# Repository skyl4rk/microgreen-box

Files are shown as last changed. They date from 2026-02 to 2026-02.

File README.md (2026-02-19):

# Microgreen Box

**An open-source, automated device that grows broccoli microgreens daily — on solar power, in a vehicle, or at home.**

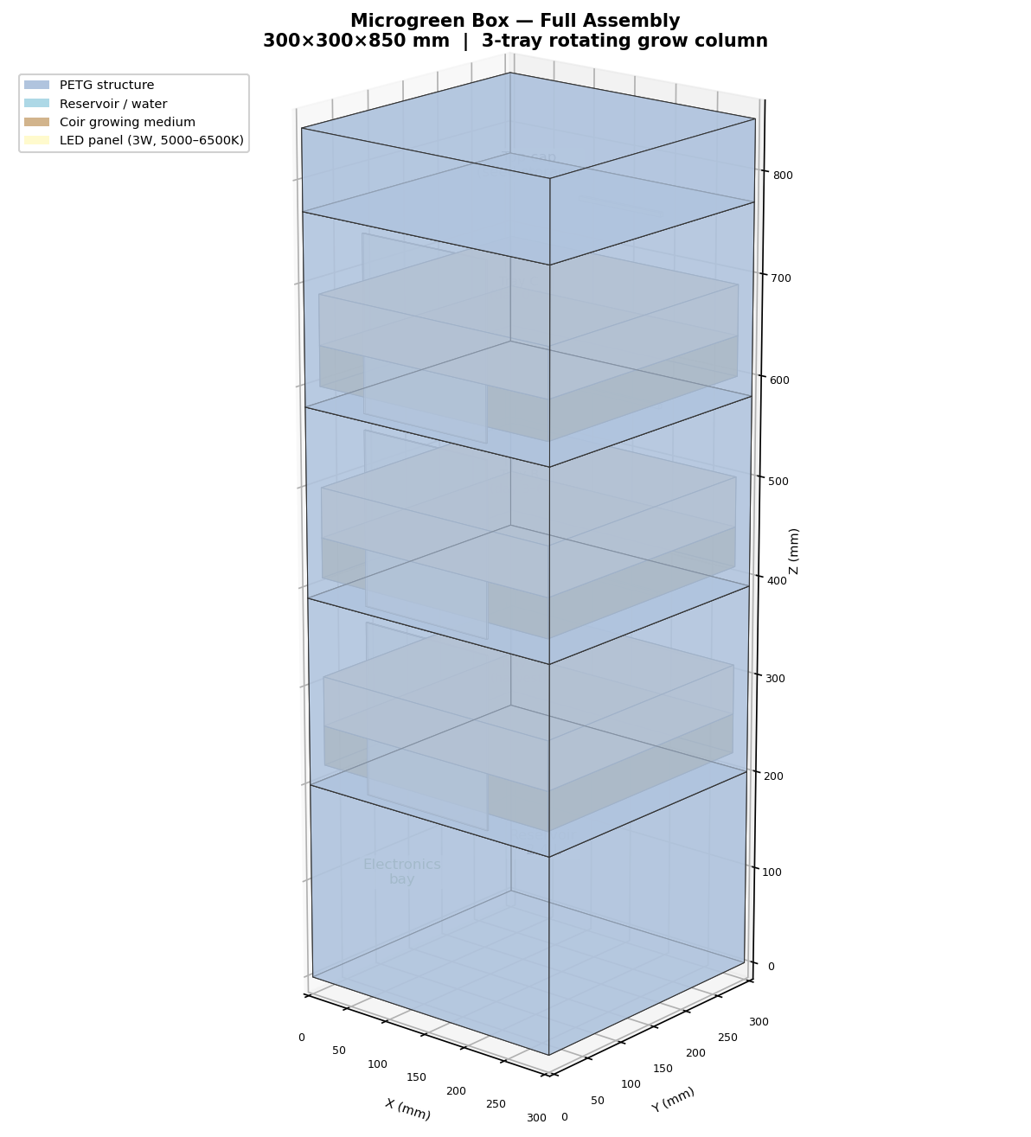
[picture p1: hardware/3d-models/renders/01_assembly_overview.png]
Assembly Overview


Broccoli microgreens contain up to 100× more sulforaphane than mature broccoli — one of the most-studied anti-cancer, anti-inflammatory compounds in food. This device automates the full grow cycle so you harvest 30 g of fresh greens every morning without daily attention.

---

## What it produces

| Output | Value |
|---|---|
| Species | Broccoli (*Brassica oleracea* var. *italica*) |
| Daily yield | 30 g/day (up to 60 g/day with 4 trays) |
| Sulforaphane dose | ~200 µmol/day (upper end of clinically studied range) |
| Grow cycle | 10 days seed-to-harvest |
| Rotation | 3 trays staggered; harvest one tray every ~3 days |
| Consumption | Raw in a morning smoothie (blending maximises sulforaphane) |

---

## Key features

- **Fully automated** — timed LED lighting, twice-daily moisture-feedback watering, harvest alert
- **12V DC power** — runs on solar + LiFePO4 battery, vehicle 12V, or a mains adapter
- **Vehicle-compatible** — sealed water system, no open surfaces, wide low-CG base
- **3D-printable** — all parts fit on a 200×200mm print bed; ~2.5 kg PETG
- **ESP32 firmware** — Arduino framework, light-sleep power management, optional OLED display, serial debug
- **Modular** — add a 4th tray ring to double output; no other changes needed
- **Open hardware** — full OpenSCAD parametric models, wiring schematics, BOM with vendor links

---

## Renders

| | |
|---|---|
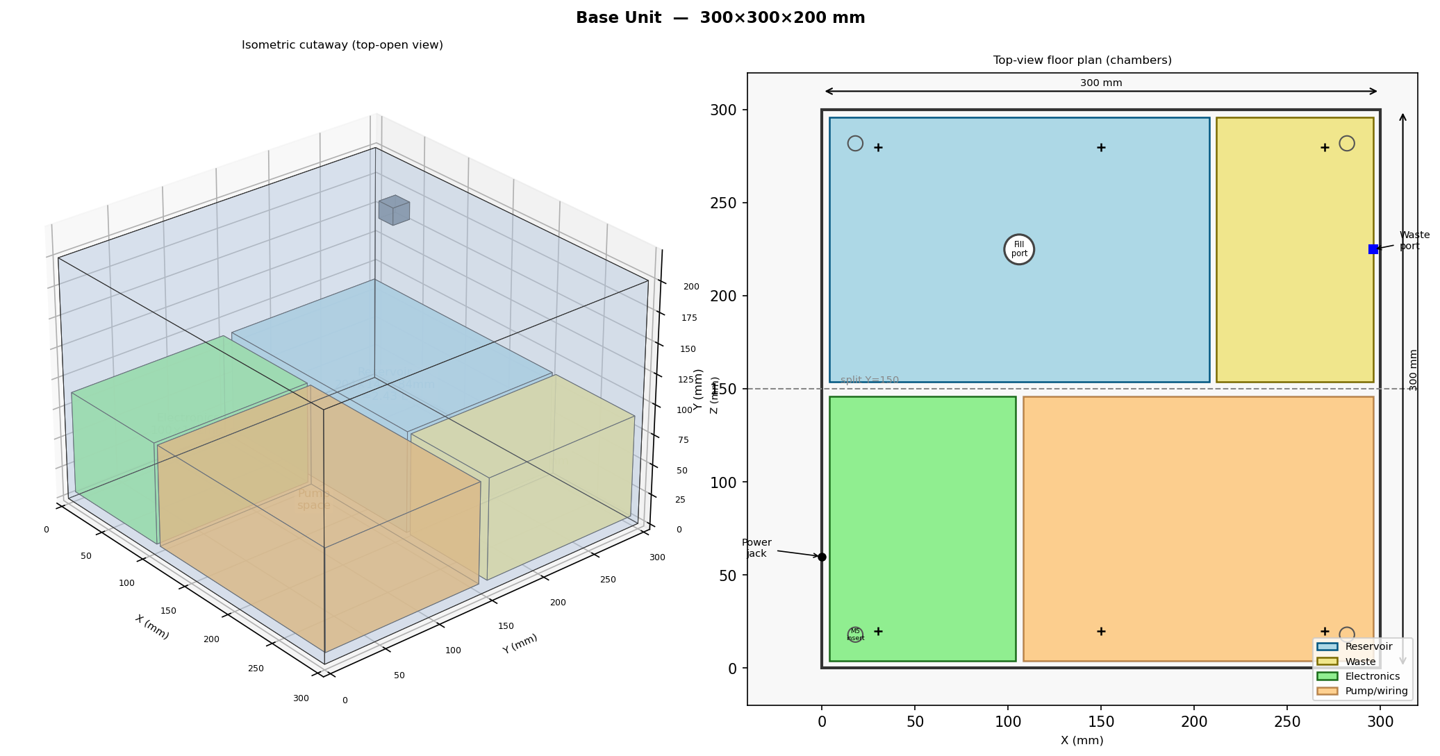
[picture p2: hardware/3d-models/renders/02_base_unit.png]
Base unit
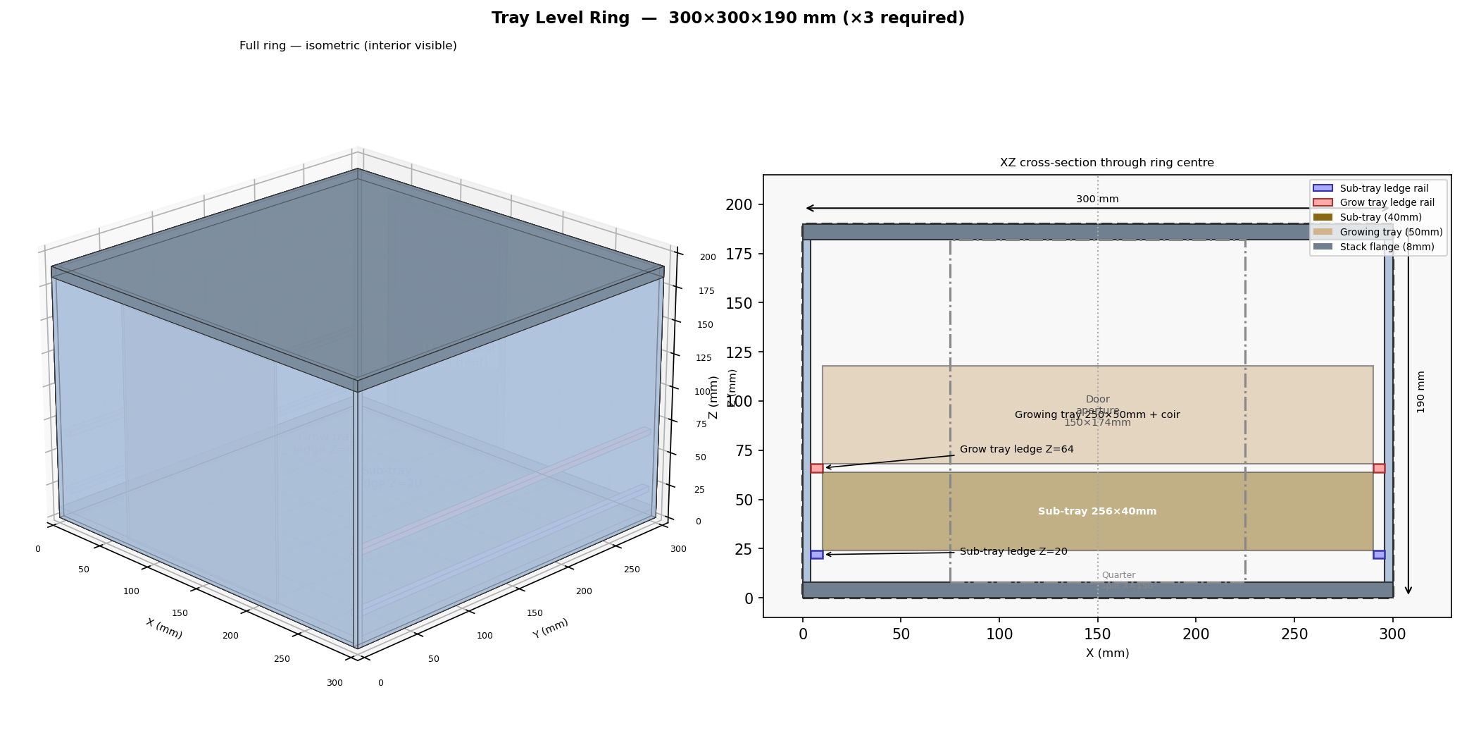
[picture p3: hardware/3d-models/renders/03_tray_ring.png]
Tray ring
|  |  |
| *Base unit — reservoir, waste chamber, electronics bay* | *Tray ring — one per grow level* |
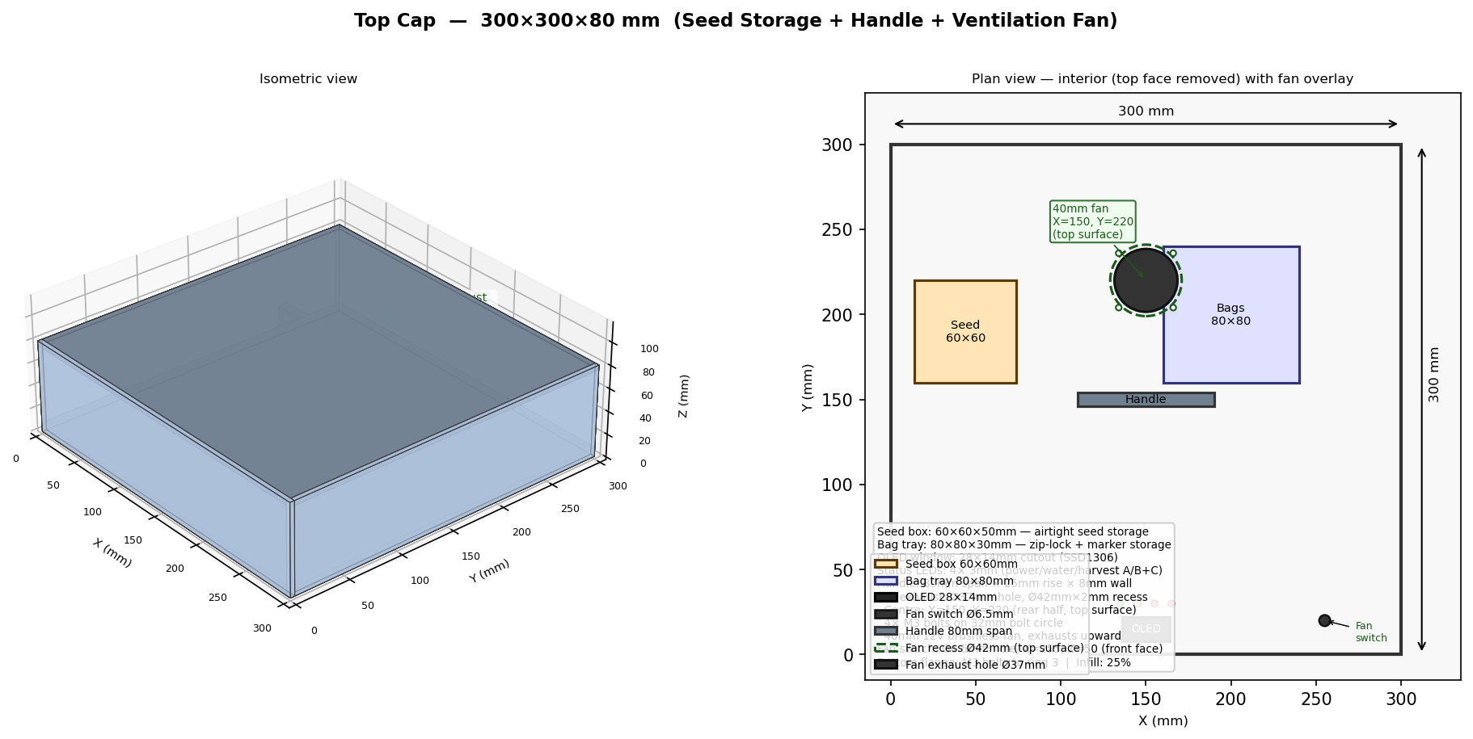
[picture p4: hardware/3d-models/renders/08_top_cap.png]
Top cap
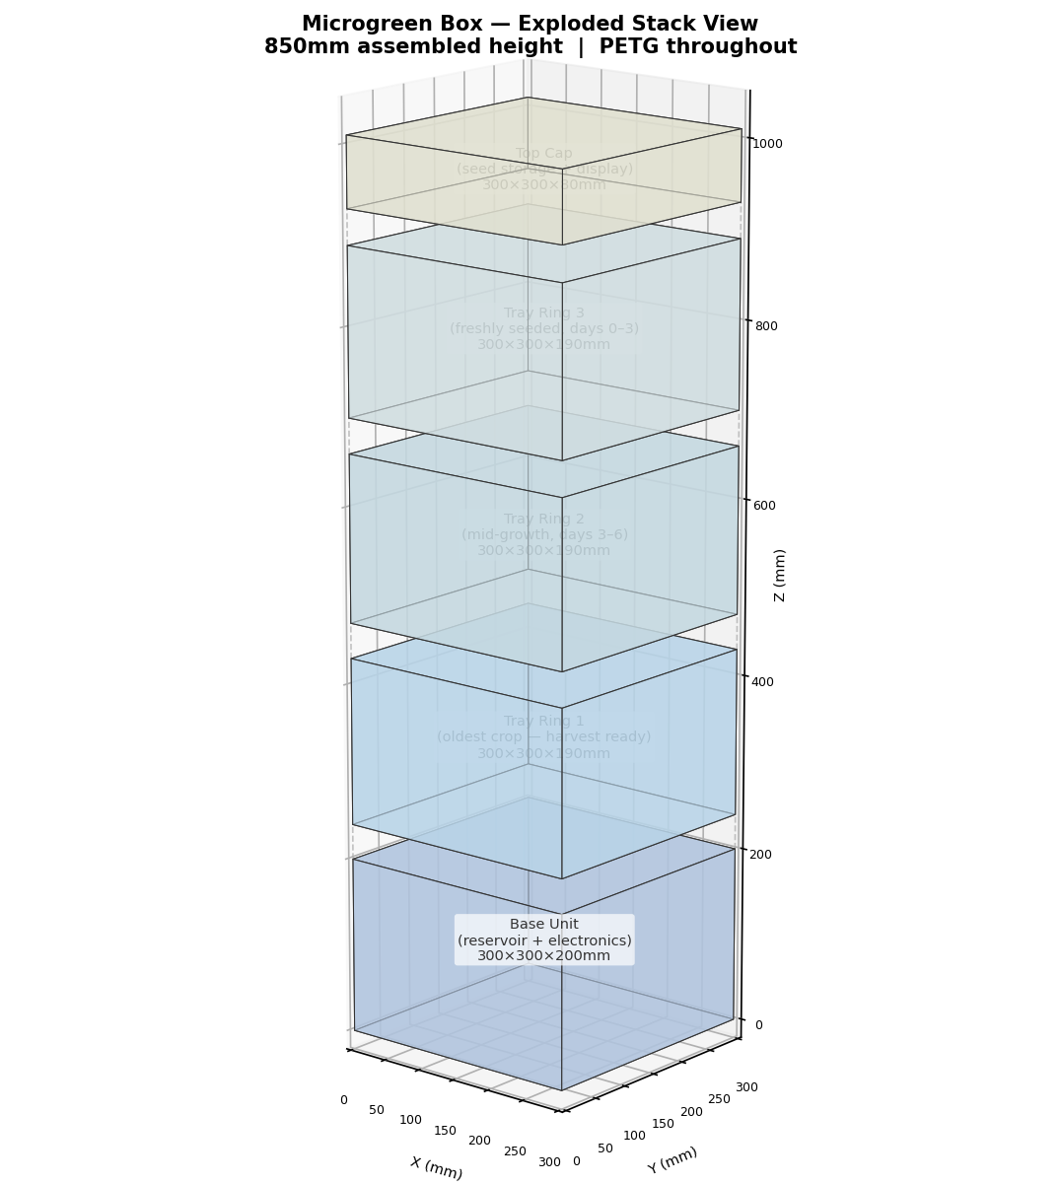
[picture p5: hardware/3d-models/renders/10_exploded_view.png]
Exploded view
|  |  |
| *Top cap — seed storage, OLED, ventilation fan* | *Exploded view — all 5 vertical sections* |

Additional renders: [hardware/3d-models/renders/](hardware/3d-models/renders/)

---

## What you need to build one

### Electronics (~$65)

| Component | Qty | ~Cost |
|---|-----|---|
| ESP32-WROOM-32 dev board | 1 | $5 |
| DS3231 RTC module | 1 | $2 |
| SSD1306 OLED display (optional) | 1 | $3 |
| MP1584EN 12V→5V buck converter | 1 | $2 |
| 4-channel relay module (JD-VCC isolated) | 1 | $3 |
| 12V peristaltic pump | 1 | $10 |
| 12V full-spectrum LED grow strips | 1 roll | $12 |
| Capacitive soil moisture sensors V1.2 | 3 | $4 |
| ZP2508 float switch | 1 | $1 |
| 40mm 12V brushless fan | 1 | $3 |
| Misc (wire, connectors, LEDs, resistors, fuse) | — | ~$20 |
| **Electronics total** | | **~$65** |

Full BOM with exact part links and vendor SKUs: [bom/bill-of-materials.csv](bom/bill-of-materials.csv)

### 3D-printed parts (~$50–62 filament)

~2.5 kg PETG filament, ~71.5 print-hours. All parts fit on a 200×200mm print bed.

**Pre-built STL files are included** in [`hardware/3d-models/stl/`](hardware/3d-models/stl/) — 20 files ready to print or upload to a print service. You do not need to install OpenSCAD to get the parts made.

**Option A — Order from a 3D print service (no printer required):**
1. Download the STL files from [`hardware/3d-models/stl/`](hardware/3d-models/stl/)
2. Upload to a service such as [Craftcloud](https://craftcloud3d.com), [JLCPCB](https://3d.jlcpcb.com), [Treatstock](https://www.treatstock.com), or a local print shop / library makerspace
3. Select **PETG** material — do not substitute PLA (it warps in hot vehicles)
4. Use the quantities listed in [`docs/03-build/printing-instructions.md`](docs/03-build/printing-instructions.md)

**Option B — Print yourself:**
See [docs/03-build/printing-instructions.md](docs/03-build/printing-instructions.md) for slicer settings. To regenerate STLs from source (only needed if you modify the design):
```bash
sudo apt install openscad
cd hardware/3d-models
make all          # regenerates all STL files in hardware/3d-models/stl/
```

### Hardware and consumables (~$30)

M3/M5 fasteners, RTV silicone, foam weather-strip, magnetic door catches, XTC-3D epoxy (waterproofing), anti-slip feet.
Broccoli seeds (~100 g/month), compressed coir pucks (3×/month).

### Optional: off-grid solar (~$100–155 additional)

40W solar panel + 20Ah LiFePO4 battery + 10A MPPT charge controller.
Average system load: ~6.6W. A 40W panel breaks even at 4 peak sun hours/day.

---

## Getting started

### 1. Read the documentation

In order:

1. [docs/02-design/system-architecture.md](docs/02-design/system-architecture.md) — how all subsystems connect
2. [docs/03-build/printing-instructions.md](docs/03-build/printing-instructions.md) — 3D printing all parts
3. [docs/03-build/assembly-instructions.md](docs/03-build/assembly-instructions.md) — 20-step build guide (written for beginners)
4. [hardware/schematics/wiring-schematic.md](hardware/schematics/wiring-schematic.md) — complete wiring reference
5. [docs/04-software/installation-guide.md](docs/04-software/installation-guide.md) — firmware setup
6. [docs/04-software/user-manual.md](docs/04-software/user-manual.md) — daily operation

### 2. Get the parts printed

**Ready-to-use STL files are in [`hardware/3d-models/stl/`](hardware/3d-models/stl/).** Upload these directly to a print service or open them in your slicer — no software installation needed.

**No printer?** Upload the STL files to an online 3D print service (Craftcloud, JLCPCB 3D, Treatstock, or a local print shop). Select **PETG** — do not substitute PLA. See [printing-instructions.md](docs/03-build/printing-instructions.md) for the quantity of each file to order and per-part infill settings to specify.

**Have a printer?** Open the STL files in PrusaSlicer, Bambu Studio, or Cura. Use 40% infill for structural parts, 4 perimeters, 6 top/bottom layers, PETG profile. Post-process reservoir and sub-tray interiors with XTC-3D epoxy for water-tightness. Full settings in [printing-instructions.md](docs/03-build/printing-instructions.md).

### 3. Wire the electronics

Follow the [assembly instructions](docs/03-build/assembly-instructions.md) step by step.
The [wiring schematic](hardware/schematics/wiring-schematic.md) has a complete wire-by-wire connection table (40+ rows).

Critical points:
- Remove the JD-VCC shorting jumper on the relay module **before** installation
- All three moisture sensor ADC pins must be on ADC1 (GPIO32/34/35) — ADC2 is disabled when WiFi is active on ESP32
- The 12V→5V buck converter powers both the ESP32 logic rail and the relay coil supply rail

### 4. Flash the firmware

```bash
# Install Arduino IDE 2.x
# Add ESP32 board support (Espressif boards URL in Preferences)
# Install via Library Manager: RTClib, Adafruit GFX, Adafruit SSD1306

# Open: software/firmware/microgreen_controller/microgreen_controller.ino
# Edit config.h for your pump flow rate and time zone offset
# Select "ESP32 Dev Module", upload to board
```

Set the clock once via serial monitor (115200 baud):

```
T1708300800    ← replace with current Unix timestamp
```

Full setup guide: [docs/04-software/installation-guide.md](docs/04-software/installation-guide.md)

### 5. Seed your first tray

1. Fill reservoir through the top fill port (2.4 L capacity, ~13 days autonomy)
2. Press the button once — three green LED flashes confirm Tray A is seeded
3. The device manages lights and watering automatically
4. On Day 8, the red harvest LED lights and the buzzer sounds — harvest and blend

Full operation guide: [docs/04-software/user-manual.md](docs/04-software/user-manual.md)

---

## Project structure

```
microgreen-box/
├── README.md                             ← you are here
├── CONTRIBUTING.md                       ← how to contribute
├── PROJECT_DECISIONS.md                  ← design decisions log (start here)
├── bom/
│   └── bill-of-materials.csv            ← 85-item BOM with vendor links and prices
├── docs/
│   ├── 01-research/                     ← nutritional research, production targets
│   ├── 02-design/                       ← system architecture, all subsystem designs
│   ├── 03-build/                        ← printing instructions, 20-step assembly guide
│   └── 04-software/                     ← firmware requirements, install guide, user manual
├── hardware/
│   ├── 3d-models/
│   │   ├── source/                      ← OpenSCAD parametric models
│   │   │   ├── params.scad              ← master dimensions (edit here first)
│   │   │   ├── base_unit.scad
│   │   │   ├── tray_ring.scad
│   │   │   ├── growing_tray.scad
│   │   │   ├── sub_tray.scad
│   │   │   ├── led_bracket.scad
│   │   │   ├── tray_door.scad
│   │   │   ├── top_cap.scad
│   │   │   └── misc_parts.scad
│   │   ├── stl/                         ← generated STL files (run `make all`)
│   │   ├── renders/                     ← PNG technical diagrams of all parts
│   │   ├── Makefile                     ← generates STLs from SCAD sources
│   │   └── render_models.py             ← generates PNG renders (matplotlib)
│   ├── schematics/
│   │   └── wiring-schematic.md          ← complete wiring reference
│   └── LICENSE                          ← CERN-OHL-S v2 (hardware)
└── software/
    ├── firmware/
    │   └── microgreen_controller/
    │       ├── microgreen_controller.ino ← main firmware sketch
    │       └── config.h                  ← all user-adjustable parameters
    └── LICENSE                           ← MIT (software/firmware)
```

---

## Design specifications

| Parameter | Value |
|---|---|
| Enclosure footprint | 300 × 300 mm |
| Enclosure height (3-tray) | 850 mm |
| Tray size | 250 × 250 mm |
| Tray count | 3 (expandable to 4 by adding a ring) |
| Growing medium | Coconut coir |
| Reservoir capacity | 2.4 L (~13 days autonomy) |
| Pump | 12V peristaltic, top-drip, 25 mL/tray/event |
| Watering schedule | Twice daily (07:00 + 19:00), moisture-feedback |
| Lighting | 3W full-spectrum LED per tray, 14h/day |
| Power input | 12V DC (5.5/2.1mm barrel jack) |
| Average power draw | ~6.6W |
| Peak power draw | ~17W (all LEDs + fan) |
| Microcontroller | ESP32-WROOM-32 (Arduino framework) |
| Enclosure material | PETG (food-safe, heat-resistant to 80°C) |
| Total build cost | ~$95 electronics + $55 filament ≈ **$150** |

---

## Firmware quick reference

All parameters in `software/firmware/microgreen_controller/config.h`:

| Parameter | Default | Description |
|---|---|---|
| `PHOTO_ON_HOUR` | 6 | Lights on (24h clock) |
| `PHOTO_OFF_HOUR` | 20 | Lights off |
| `BLACKOUT_DAYS` | 2 | Germination darkness days per tray |
| `GERMINATION_WATER_DAYS` | 2 | Watering exclusion window (days 0–N) |
| `WATER_HOUR_1` | 7 | First daily watering event |
| `WATER_HOUR_2` | 19 | Second daily watering event |
| `GROW_DAYS` | 10 | Full grow cycle length |
| `HARVEST_DAY` | 8 | Day harvest alert activates |
| `PUMP_RUN_SECONDS` | 90 | Pump run time — **calibrate to your pump** |
| `MOISTURE_SKIP_THRESHOLD` | 70 | Skip watering if moisture above this % |
| `MOISTURE_TOPUP_THRESHOLD` | 25 | Extra pump run if moisture below this % |

Serial commands (115200 baud): `T<epoch>` sets RTC clock, `S` dumps full device status.

---

## Nutrition context

Broccoli microgreens at 30 g/day provide approximately:

- **~200 µmol sulforaphane potential** (via glucoraphanin + myrosinase, activated by blending)
- Clinical studies typically use 50–150 µmol/day for anti-inflammatory and chemoprotective effects
- 10–100× more sulforaphane per gram than mature broccoli
- Must be consumed raw — myrosinase enzyme is destroyed above ~70°C

For maximum sulforaphane: blend fresh (or blend from frozen — raw home freezing increases yield up to 3.1×).

Research background: [docs/01-research/](docs/01-research/)

---

## License

This project uses a dual licence:

| Component | Licence |
|---|---|
| Hardware (3D models, schematics) in `hardware/` | [CERN-OHL-S v2](hardware/LICENSE) |
| Software/firmware in `software/` | [MIT](software/LICENSE) |
| Documentation in `docs/` | [CC-BY-SA 4.0](https://creativecommons.org/licenses/by-sa/4.0/) |

The CERN-OHL-S licence is **strongly reciprocal**: if you build modified hardware and distribute it, you must publish the modified source files under the same licence.

---

## Contributing

Bug reports, build logs, and improvements welcome. See [CONTRIBUTING.md](CONTRIBUTING.md).

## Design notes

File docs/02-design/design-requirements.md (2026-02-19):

# Design Requirements

**Phase:** 02 Design
**Status:** Complete
**Last Updated:** 2026-02-17

---

## Summary

This document translates all Phase 01 research findings and the claude.md design goals into specific, measurable engineering requirements. All subsystem designs must satisfy these requirements. Any proposed design change that conflicts with a requirement listed here must be flagged and resolved in PROJECT_DECISIONS.md before proceeding.

---

## Source Constraints (from claude.md)

The following constraints are non-negotiable design goals from the project brief:

| Constraint | Value |
|---|---|
| Power supply | 12V or 5V DC from solar panel / battery system |
| Operating environment | Must function in a moving vehicle |
| Cost | Low cost; 3D-printed structure + low-cost supplier parts |
| Structure | All structural parts 3D printable (PETG preferred) |
| Inputs | Minimal: broccoli seed, water, coir |
| Interaction | Minimal human interaction; ideally only at harvest and seeding |
| Scalability | Easily scalable for multiple persons |
| Output | Daily dose in an easily usable form |
| Autonomy | 7+ days unattended operation (reservoir capacity) |

---

## Functional Requirements

| ID | Requirement | Value | Source | Priority |
|----|---|---|---|---|
| FR-001 | Device shall produce fresh broccoli microgreens at the daily target rate | **30 g/day (primary), 60 g/day (max)** | DECISION-002 | Must |
| FR-002 | Device shall support a staggered 3-tray rotation for continuous harvest | **3 trays, one harvested every ~3 days** | DECISION-005 | Must |
| FR-003 | Device shall operate on 12V DC primary power | 12V nominal (±10%) | claude.md | Must |
| FR-004 | Device shall provide automated lighting on a configurable schedule | **14h on / 10h off** default; 0h during germination phase | FINDING-009, claude.md | Must |
| FR-005 | Device shall provide automated watering on a configurable schedule | **2× per day, ~25 mL per tray per event** | Broccoli microgreen literature | Must |
| FR-006 | Device shall contain all water in sealed reservoirs and sealed sub-trays | No open water surfaces; sealed fittings | claude.md (vehicle use) | Must |
| FR-007 | Device shall deliver harvested greens in a fresh, cut-ready state | No processing; user harvests by cutting | DECISION-003, DECISION-004 | Must |
| FR-008 | Device shall operate the germination phase without light | Software-controlled per-tray light inhibit for days 0–2 | Broccoli grow protocol | Must |
| FR-009 | Device shall alert the user when the water reservoir is low | Low-water indicator (LED or buzzer) | — | Must |
| FR-010 | Device shall alert the user when a tray is ready to harvest | Day-count indicator (LED or display) | — | Should |
| FR-011 | Device shall be scalable by stacking additional tray modules | Modular vertical design; each module adds one tray level | claude.md | Should |
| FR-012 | Device shall use coir as growing medium (not soil/compost) | See DECISION-007; vehicle-compatible | claude.md, DECISION-007 | Must |

---

## Non-Functional Requirements

| ID | Requirement | Value | Rationale | Priority |
|----|---|---|---|---|
| NFR-001 | Autonomous operation between user interactions | **≥7 days** (water reservoir, seed pre-loaded) | Minimal interaction goal | Must |
| NFR-002 | Maximum enclosure footprint | **≤35 × 35 cm** | Kitchen/vehicle counter space | Must |
| NFR-003 | Maximum enclosure height (3-tray primary) | **≤90 cm** | Practical for vehicle/countertop | Should |
| NFR-004 | Silent operation | Pump noise ≤ 50 dB at 1m during water cycle | Vehicle and home use | Should |
| NFR-005 | Total BOM cost (electronics + consumables, excluding solar) | **≤ USD $150** | Low-cost design goal | Must |
| NFR-006 | Structural parts 3D-printable in PETG | All enclosure and tray parts print on standard FDM printer (200×200 mm bed minimum) | claude.md | Must |
| NFR-007 | Food-safe material contact | Growing trays, sub-trays, and water paths use PETG or food-safe ABS; no PLA near water | Food safety | Must |
| NFR-008 | Stable under vehicle motion | No tipping, no spill; center of gravity ≤50% of base width | claude.md | Must |
| NFR-009 | PPFD at tray surface | **80–120 µmol/m²/s** | FINDING-009: balanced nutrient profile | Must |
| NFR-010 | Growing medium mineral quality | Coir + optional dilute liquid mineral supplement in water (CalMag or equivalent) | DECISION-007 | Should |

---

## Power Budget

| Load | Peak Power | Avg Power (daily profile) | Notes |
|---|---|---|---|
| LED panel (per tray) | 3W | 1.75W (14h/24h) | 3 trays = 9W peak, 5.25W avg |
| Peristaltic pump | 5W | 0.035W (6 min/day) | 2 events/day × 3 trays |
| ESP32 MCU | 0.3W | 0.25W | Light sleep between events |
| RTC module | 0.01W | 0.01W | DS3231 or similar |
| Water level sensor | 0.1W | 0.05W | Periodic polling |
| Status LEDs | 0.1W | 0.05W | 3mm indicator LEDs |
| **Total** | **~14.5W peak** | **~5.6W avg** | |

**Daily energy: 5.6W × 24h = ~134 Wh/day**
**Average current at 12V: 134 / (12 × 24) = 0.47 A**
**Peak current at 12V: 14.5 / 12 = 1.2 A**

---

## Power Supply Requirements

| Mode | Specification |
|---|---|
| Primary input | 12V DC, ≥2A (24W) continuous |
| Peak demand | 12V DC, ≥2A (14.5W — within 2A with margin) |
| Solar (off-grid) | 40W panel minimum; 50W recommended |
| Battery (off-grid) | 20Ah LiFePO4 at 12V (= ~192 Wh usable at 80% DoD) |
| MPPT controller | 10A, 12V/24V auto |
| Autonomy (full battery, no solar) | ~34 hours (192Wh / 5.6W avg) |
| Autonomy (40W solar, 4 sun hours) | Indefinite — 40×4×0.85=136 Wh/day > 134 Wh/day |
| Mains alternative | 12V/2A DC wall adapter (≈$10) |

---

## Interface Requirements

| Interface | Specification |
|---|---|
| Power input | 5.5/2.1mm barrel jack, 12V DC |
| Solar input | Via MPPT controller (external) |
| User indicators | 4× 3mm LEDs: Power, Water Low, Tray A ready, Tray B/C ready |
| Optional display | 0.96" OLED I2C (addressable via ESP32) |
| Connectivity | WiFi (ESP32 built-in); not required for operation |
| Water fill port | Top-access sealed cap on reservoir |
| Harvest access | Front-opening door or top-slide tray extraction |
| Seed/coir loading | Tray removal for manual loading |

---

## Constraints Summary

| ID | Constraint | Value |
|----|---|---|
| C-001 | Footprint | ≤35×35 cm |
| C-002 | Average power draw | ≤10W (target 5.6W) |
| C-003 | Peak power draw | ≤15W |
| C-004 | Primary voltage | 12V DC |
| C-005 | BOM cost (excl. solar) | ≤$150 USD |
| C-006 | Growing medium | Coir only (vehicle safe, see DECISION-007) |
| C-007 | Water containment | Fully sealed — no open water surfaces |
| C-008 | Material (food contact) | PETG or food-safe equivalent |
| C-009 | 3D printability | Max part size ≤ 200×200×200 mm |
| C-010 | Scalability | Adding one tray module must not require redesign of base |

---

## Resolved Open Questions

| Q-ID | Question | Resolution |
|---|---|---|
| Q-002 | Blackout / germination duration | Days 0–2 (48h) LED off per tray; controlled by MCU day counter |
| Q-006 | Seeding density | 12–15 g seed per 625 cm² tray; 0.019–0.024 g/cm² |
| Q-007 | Water recirculation | Drain-to-waste within sealed enclosure (waste sub-reservoir); no recirculation for simplicity |

## Remaining Open Questions

| Q-ID | Question | Priority |
|---|---|---|
| Q-001 | Actual yield of 25×25cm tray with coir under 100 µmol/m²/s | High — validate by prototype |
| Q-003 | Automated harvest notification vs. simple timer LED | Low |
| Q-004 | Fresh shelf life with dry refrigerated storage | Medium |
| Q-005 | @continuousharvest5822 YouTube channel review | Medium |

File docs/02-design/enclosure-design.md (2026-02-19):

# Enclosure Design

**Phase:** 02 Design
**Status:** Complete
**Last Updated:** 2026-02-17

---

## Summary

The enclosure is a vertical column, 30 × 30 cm footprint × 85 cm tall, 3D-printed in PETG. It consists of stackable ring sections (one per tray level), a base unit (reservoir + electronics bay), and a top cap (seed storage + optional OLED display). All parts print on a 200×200mm print bed. The design is modular: adding a 4th tray requires only one additional ring section. Vehicle stability is achieved through a wide base and optional mounting bracket.

---

## Overall Dimensions

| Dimension | Value | Notes |
|---|---|---|
| Footprint (external) | 300 × 300 mm | Fits within 35×35cm constraint |
| Height (3-tray + base + cap) | ~850 mm | Within 90cm NFR target |
| Height (4-tray, scalable) | ~1100 mm | |
| Wall thickness | 4 mm | PETG structural strength |
| Internal width | 292 mm | 300 − 2×4mm walls |
| Material | PETG | Moisture-resistant, food-safe, high temp tolerance |
| Interior finish | White or reflective silver liner | Maximizes LED light reflection |
| Exterior finish | Matte black or user choice | Any PETG colour |

---

## Assembly Sections

The enclosure is made up of printed sections that stack and lock together:

### 1. Base Unit (300×300×200mm)

Contains:
- **Water reservoir** (2.4L sealed chamber, 204×142×84mm internal, rear-left quadrant)
- **Waste chamber** (1.0L sealed, 84×142×84mm internal, rear-right quadrant)
- **Electronics bay** (100×140×84mm, front-left quadrant, sealed from water zone by PETG partition + silicone gasket)
- **Power inlet** (5.5/2.1mm barrel jack, side-mounted)
- **Water fill port** (top-access screw cap, Ø40mm, positioned above reservoir)
- **Anti-slip pad** (4× silicone feet, press-fit into recesses on base bottom)
- **Vehicle mounting points** (4× M5 threaded inserts on base corners, for strap or bracket attachment)

Internal partition wall between electronics bay and water zone: PETG wall + RTV silicone bead. Any water condensation or micro-leak stays in the water zone.

### 2. Tray Level Ring (300×300×190mm per level — 3 required)

Each ring section contains one complete grow level:

```
┌─ LED Panel bracket (top of ring) ──────────────────┐
│  LED panel mounts to 3D-printed bracket, 10cm      │
│  above tray surface. Adjustable ±3cm via slot.     │
├─ Growing tray slot (middle of ring) ───────────────┤
│  Tray slides in from front; 5mm lip on both sides  │
│  holds tray in place during vehicle motion.        │
├─ Sub-tray slot (bottom of ring) ───────────────────┤
│  Sub-tray seated in lower pocket; drain fitting    │
│  routes to waste chamber tubing.                   │
└────────────────────────────────────────────────────┘
```

| Dimension | Value |
|---|---|
| Outer | 300 × 300 × 190 mm |
| Tray opening | 256 × 256 mm (tray slides in from front) |
| Front door | Hinged PETG panel with magnetic catch |
| Interior height clearance (tray to LED) | ~80–110 mm (adjustable via LED bracket slot) |
| Drip inlet port | Ø8mm hole in rear wall for drip tubing |
| Drain outlet port | Ø8mm hole in base of sub-tray pocket |
| Stack connector | 6× M3 bolt holes top and bottom; sections bolt together |
| Print strategy | 4 L-shaped corner quarters (FL, FR, RL, RR) each ≤ 200×200mm |

**Front door:** Each tray level has a hinged PETG panel (150×174mm) with a magnetic catch. To harvest, open the door and slide out the growing tray. Door seals against a foam weather-strip to exclude light (important during adjacent tray germination phases).

### 3. Top Cap (300×300×80mm)

Contains:
- **Seed storage compartment** (60×60×50mm sealed box with lid)
- **Bag/marker storage** (open tray, 80×80×30mm)
- **Optional OLED display window** (Ø30mm or 40×20mm cutout, with clear PETG lens glued in place)
- **Handle / lift point** (integral loop handle on top surface)
- **Status LED window** (4× 3mm holes for indicator LEDs)
- **Ventilation fan mount** (37mm exhaust hole + 42mm recess + 4× M3 holes at fan rear; 40mm fan exhausts upward — DECISION-024)
- **Toggle switch cutout** (6.5mm panel-cut hole in front face right side for fan on/off switch)

---

## Print Strategy

All parts must fit on a 200×200mm print bed. Parts larger than this are split and joined with M3 hardware + PETG solvent weld or press-fit.

Each tray ring is printed as **4 L-shaped corner quarters** (FL=front-left, FR=front-right, RL=rear-left, RR=rear-right), each fitting on a 200×200mm bed — see DECISION-013.

| Part | Print bed needed | Qty | Est. filament | Est. print time |
|---|---|-----|---|---|
| Base unit front half | 200×200mm | 1 | 310g | 9h |
| Base unit rear half | 200×200mm | 1 | 310g | 9h |
| Tray ring FL quarter | 200×200mm | 3 | 100g each | 3h each |
| Tray ring FR quarter | 200×200mm | 3 | 100g each | 3h each |
| Tray ring RL quarter | 200×200mm | 3 | 95g each | 2.5h each |
| Tray ring RR quarter | 200×200mm | 3 | 95g each | 2.5h each |
| Growing tray | 200×200mm | 3 | 60g each | 2h each |
| Sub-tray | 200×200mm | 3 | 50g each | 1.5h each |
| Top cap | 200×200mm | 1 | 95g | 3h |
| LED bracket | 200×200mm | 3 | 20g each | 0.5h each |
| Front door | 200×200mm | 3 | 30g each | 1h each |
| Misc (clips, manifold, emitters, LED panel) | 200×200mm | 1 set | 100g | 4h |
| **Total** | | | **~2,465g** | **~71.5h** |

**Total filament: approximately 2.5 kg PETG (~$50–62 at $20–25/kg)**

**Total print time: approximately 71.5 hours** (7–9 days on a single printer at normal speed; parallelizable across multiple printers)

---

## Print Settings

| Parameter | Value | Notes |
|---|---|---|
| Material | PETG | Moisture-resistant; food-safe; better than PLA for this application |
| Layer height | 0.2mm | Standard quality |
| Infill | 25% (decorative), 40% (structural: base, tray rings) | Higher infill for load-bearing parts |
| Wall perimeters | 4 | Critical for water-tight walls |
| Top/bottom layers | 6 | Helps with water resistance |
| Print temperature | 235–240°C (PETG typical) | Tune for your specific filament |
| Bed temperature | 70–85°C |  |
| Cooling | Moderate (50% fan) | Too much cooling causes PETG layer delamination |
| Supports | None (designed to print without supports) | Parts oriented for support-free printing |
| Water tightness | Post-process: apply XTC-3D epoxy coating or spray shellac to inner surfaces of reservoir | Ensures no weeping through layer lines |

---

## Material

**PETG (Polyethylene Terephthalate Glycol)**

| Property | Value | Relevance |
|---|---|---|
| Food safety | Generally food-safe (FDA food contact materials list) | Growing trays, water reservoir |
| Heat resistance | 80°C glass transition | Safe in vehicles (max interior: typically 60°C with windows closed) |
| UV resistance | Moderate | Better than PLA; acceptable indoors/in-vehicle |
| Moisture resistance | Excellent | Critical for water contact parts |
| Layer adhesion | Good | Important for water-tight printing |
| Flexibility | Slight | Reduces brittleness vs. PLA |
| Shrinkage | Low | Good dimensional accuracy |
| Cost | $20–25/kg | Mid-range |

**Do not use PLA for water-contact or heat-exposed parts.** PLA has a glass transition of only 60°C and will warp in a hot vehicle. PLA also degrades in moist environments over time. PETG is mandatory for all water-adjacent and structurally loaded parts. PLA may be used for decorative external parts only.

---

## Structural Design for Vehicle Use

| Challenge | Design solution |
|---|---|
| Tipping | Wide 300mm base; low center of gravity (water reservoir at base) |
| Tray sliding out | Each tray has a 5mm positive-lock lip; requires deliberate pull to remove |
| LED panel vibration | LED panel retained by 2× M3 bolts; no loose parts |
| Tubing vibration | All tubing secured every 50mm with 3D-printed clip-on saddles |
| Door rattling | Magnetic door catch; foam weather-strip around door perimeter |
| Vehicle mounting | 4× M5 inserts in base corners; user provides strap or custom bracket for their vehicle |

**Center of gravity:** With full reservoir (2kg water) at the base and minimal mass at the top, CG is approximately 200mm above the base — well within the 150mm (50% of 300mm base) stability limit.

---

## Ventilation

At 5.6W average power, the growing chamber temperature should remain close to ambient. Two complementary ventilation modes are available: passive (always available) and active (manual on-demand).

### Passive Ventilation — Ring Vent Slots

Each tray ring has two **25×8mm vent slots** (one in the front wall, one in the rear wall), positioned near the top of the ring (Z = ring_h − flange_h − 12mm). Each slot has a removable slide cover.

- **Normal operation:** Slide covers in place — ring is light-sealed during germination blackout periods.
- **Enhanced ventilation:** Remove slide covers on one or more rings — allows passive stack convection from lower rings upward.
- **Airflow path (passive):** Ambient air enters through lower ring vent slots → rises through the column (warm air from LED strips creates convection) → exits through any open upper slots or the active fan.

### Active Ventilation — 40mm 12V Fan with Manual Switch (DECISION-024)

A **40mm 12V brushless fan** is mounted in the top cap top surface and exhausts upward. It is controlled by a **manual SPST toggle switch** on the top cap front face — no firmware involvement.

| Parameter | Value |
|---|---|
| Fan size | 40×40×10mm, 12V DC |
| Airflow | ~5–8 CFM (adequate for 56L column) |
| Noise | ≤25 dBA (brushless PC fan) |
| Power | ~1–1.8W at 12V (manual, not always on) |
| Fan location | Top cap top surface, centred at X=150mm, Y=220mm |
| Switch location | Top cap front face, right side, X=255mm, Z=50mm |
| Circuit | 12V bus → toggle switch → fan (no relay, no firmware) |

**Airflow path (active):** Ambient air enters through ring vent slots (slide covers open) → rises through column → exhausts upward via top cap fan.

**When to use the fan:**
- Surface mould or white fuzz observed on coir
- Persistent condensation on ring interior walls
- Ambient temperature above 28°C (vehicle in direct sun)
- During watering events in high-humidity environments

**Temperature target inside growing chamber: 18–24°C.** Broccoli microgreens tolerate 15–27°C but perform best at 20–22°C.

---

## Light Sealing

Each tray level must be light-sealed to ensure the germinating tray (LED off) is not illuminated by adjacent tray LEDs. The ring sections achieve this via:
- 2mm light-seal flange at every section join
- Black PETG or black felt strip at all section interfaces
- Front door foam weather-strip (3mm closed-cell foam, adhesive-backed)

This ensures that a tray in blackout phase stays dark even if the tray below it has its LED on.

---

## Enclosure BOM Estimate

| Item | Qty | Unit Cost | Total |
|---|-----|---|---|
| PETG filament | 2.4 kg | $22/kg | $53 |
| M3 bolt/nut kit (50 pcs each) | 1 | $5 | $5 |
| M5 heat-set inserts (4×) | 1 | $2 | $2 |
| Magnetic door catches (3 pairs) | 1 | $3 | $3 |
| Foam weather-strip (3m) | 1 | $4 | $4 |
| Silicone anti-slip feet (4×) | 1 | $2 | $2 |
| XTC-3D epoxy (reservoir waterproofing) | 1 | $15 | $15 |
| O-ring for fill cap (Ø36mm) | 1 | $1 | $1 |
| Clear PETG sheet (OLED window) | 1 | $3 | $3 |
| **Enclosure total** | | | **~$88** |

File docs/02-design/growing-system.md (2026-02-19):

# Growing System Design

**Phase:** 02 Design
**Status:** Complete
**Last Updated:** 2026-02-17

---

## Summary

The growing system consists of 3 identical tray levels in a vertical column. Each level holds a 25×25 cm growing tray filled with coir growing medium and broccoli seeds, sitting above a sealed sub-tray that serves as a water retention and drainage chamber. Trays are seeded on a staggered 3-day interval, providing a harvest every ~3 days at approximately 90–130 g per event. This yields ~30–43 g/day, meeting the primary 30 g/day target.

---

## Growing Medium: Coir

**Selected medium:** Compressed coconut coir (available as pucks or bricks)

### Why Coir (Amendment to DECISION-006)

Original DECISION-006 specified compost/soil for 73% higher mineral content. However, **claude.md specifies coir as a required input** and mandates vehicle-compatible operation. Compost/soil is not suitable for a vehicle: it is heavy, prone to spillage during motion, and significantly messier for user handling. See DECISION-007 in PROJECT_DECISIONS.md for the full decision record.

**Resolution:** Coir growing medium with an optional dilute liquid mineral supplement (CalMag or equivalent) added to the watering solution. This partially recovers the mineral density difference while maintaining vehicle compatibility.

### Coir Properties

| Property | Value |
|---|---|
| Form | Compressed puck or brick (expands 6–8× when wetted) |
| pH | 5.5–6.8 (ideal for broccoli: 6.0–7.0) |
| Texture | Fibrous; excellent water retention and air pockets |
| Weight dry | ~8 g per 25×25 cm tray (from 50 g coir puck compressed) |
| Weight wet | ~200–250 g per tray at field capacity |
| Mineral content | Low (negligible inherent minerals vs. compost) |
| Vehicle stability | Excellent — fibrous mat, does not slosh or spill |
| Reusability | Single use per grow cycle; compostable after use |
| Source | Compressed coir pucks: widely available, $5–15 for 10–20 pucks |

### Mineral Supplement Protocol

To partially compensate for coir's low inherent mineral content:
- Add CalMag liquid supplement at **0.5 mL per liter of water** (quarter-strength dilution)
- Apply from day 3 onward (not during germination to avoid seed burn)
- Optional — device produces nutritionally valuable microgreens even without supplement

---

## Tray Design

### Growing Tray (inner dimensions)

| Dimension | Value |
|---|---|
| Inside width | 250 mm |
| Inside depth | 250 mm |
| Inside height | 50 mm |
| Wall thickness | 3 mm |
| Outer dimensions | 256 × 256 × 53 mm |
| Drain holes | 4× Ø8mm holes in base (covered by coir mat) |
| Material | PETG (food-safe, moisture resistant) |
| Print time (estimate) | ~4–6 hours |

Drain holes allow excess water from top-drip to pass through into the sub-tray below. The coir mat naturally filters the water; roots do not block the holes at the cotyledon stage.

### Sub-Tray (water retention / sealed drainage)

| Dimension | Value |
|---|---|
| Inside width | 256 mm (matches growing tray outer width) |
| Inside depth | 256 mm |
| Inside height | 40 mm |
| Drain outlet | Ø8mm fitting on one side wall, connects to waste chamber tubing |
| Overflow threshold | 25 mm (sub-tray holds up to 25mm = ~163 mL before overflowing to waste) |
| Material | PETG |
| Lid/seal | Growing tray sits on top of sub-tray with 3mm lip for stability |

The sub-tray catches all drain water from the growing tray. Passive overflow fitting drains to the waste chamber at the base when sub-tray fills beyond 25mm. This creates a stable, sealed water path with no open surfaces — critical for vehicle use.

---

## Seeding Specifications

| Parameter | Value | Notes |
|---|---|---|
| Seed variety | Broccoli (*Brassica oleracea*) — microgreen grade | De Cicco, Calabrese, or similar dense-seeding cultivar |
| Seed quantity per tray | **12–15 g** per 625 cm² tray | ~0.19–0.24 g/cm² |
| Pre-soak | **4–8 hours in water** before planting | Improves germination rate and uniformity |
| Seeding method | Scatter evenly over moistened coir; press lightly | No burial needed; broccoli germinates at surface |
| Post-seed | Cover with blackout lid (or simply disable tray LED); keep moist | Germination in dark, humid environment |
| Germination rate | 85–95% expected | Broccoli seeds germinate reliably |
| Coir prep | Expand coir puck in 300 mL warm water; squeeze to ~field capacity; fill tray | Coir should be damp but not dripping |

---

## Grow Cycle Stages

| Stage | Days | Light | Watering | Notes |
|---|---|---|---|---|
| Germination | Days 1–2 | **OFF** (blackout) | Once on day 1 (~25mL mist); check moisture on day 2 | Seeds need dark, humid, ~20–24°C |
| Early growth | Days 3–5 | **ON** (14h/day) | 2× daily, 25 mL per event | First true stem extension; etiolation phase ends |
| Active growth | Days 6–8 | **ON** (14h/day) | 2× daily, 25–30 mL per event | Cotyledons open; green color develops |
| Harvest window | Days 8–10 | **ON** | Normal watering | Cut when cotyledons fully open and stem is 3–5 cm tall |
| Maximum hold | Day 11 | Turn off | Reduce watering | Do not leave past day 11; quality and GRN decline |

**Blackout on days 1–2:** The MCU tracks the seeding date for each tray and suppresses the LED for that tray level during the first 2 days. No physical blackout cover is required — software-controlled.

---

## Rotation Schedule

Three trays (A, B, C) are staggered with a 3-day seeding interval:

```
Day  Tray A       Tray B       Tray C
───  ──────────   ──────────   ──────────
 1   Seed day 1   —            —
 2   Germ (dark)  —            —
 3   Light on     —            —
 4   Growing      Seed day 1   —
 5   Growing      Germ (dark)  —
 6   Growing      Light on     —
 7   Harvest      Growing      Seed day 1
     window
 8   ─HARVEST─    Growing      Germ (dark)
     (reseed A')
 9   Germ (dark)  Harvest win  Light on
10   Light on     ─HARVEST─    Growing
                  (reseed B')
11   Growing      Germ (dark)  Harvest win
12   Growing      Light on     ─HARVEST─
                               (reseed C')
13   ─HARVEST─    Growing      Germ (dark)
     (reseed A'')
...  (cycle repeats every 9–10 days per tray)
```

**Steady state (after day 8):**
- A tray is harvested approximately every **3 days**
- Each harvest yields **~90–130 g** fresh microgreens
- 90 g / 3 days = **30 g/day** (conservative)
- 130 g / 3 days = **43 g/day** (typical)

---

## Harvest Procedure (User Workflow)

1. When harvest LED illuminates (day 8–10 for that tray):
2. Open the enclosure door / slide out the tray level
3. Using scissors or a sharp knife, cut stems at the coir line
4. Place cut greens in a container
5. **Refrigerate 30g immediately** (next 2–3 days)
6. **Freeze remainder** in pre-weighed 30g portions in sealed zip bags
   - Label with date
   - Place flat in freezer
   - Use within 3–6 months; blend from frozen directly into smoothie
7. Remove spent coir from tray (compost or discard)
8. Rinse and dry tray and sub-tray
9. Prep fresh coir, pre-soak seeds, reseed
10. Reset the MCU tray counter (press button or automatic after re-insertion)
11. Return tray to enclosure — cycle restarts

**Total user time per harvest event: ~5–10 minutes**
**User interactions per week: ~2 (harvest once, top up water reservoir)**

---

## Expected Yield Summary

| Condition | Yield per Tray | Daily Average (3-tray, 3-day harvest) |
|---|---|---|
| Conservative (coir, basic light) | 80 g | 27 g/day |
| Expected (coir, 100 µmol/m²/s) | 110 g | 37 g/day |
| Optimistic (dense seed, CalMag) | 130 g | 43 g/day |

**All scenarios meet or approach the 30 g/day primary target. The target is conservative; actual yield is expected to exceed it after the user optimizes seeding density.**

---

## Seed Storage

- Store seed in a sealed, opaque container
- Location: cool, dry, dark — seed storage shelf inside top cap of enclosure
- Storage capacity: 100 g (≈6–7 tray cycles); replenish monthly
- Shelf life: 2–3 years in dry storage
- Source: bulk broccoli microgreen seed, ~$15–30/kg

---

## Growing System BOM Estimate

| Item | Qty | Unit Cost | Total |
|---|-----|---|---|
| PETG filament (trays + sub-trays) | ~800g | $0.025/g | $20 |
| Coir pucks (50g each, ~1/tray) | 24/year | $0.50–1.00 | $12–24/yr |
| Broccoli microgreen seed | 200g/yr | $5–10 | $10–20/yr |
| CalMag liquid supplement (optional) | 1 bottle/yr | $10 | $10/yr |
| **Growing system hardware total** | | | **~$20 one-time + $32–54/yr consumables** |

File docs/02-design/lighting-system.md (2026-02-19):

# Lighting System Design

**Phase:** 02 Design
**Status:** Complete
**Last Updated:** 2026-02-17

---

## Summary

Each of the 3 tray levels has a dedicated 12V LED grow panel mounted directly above the growing tray at 10 cm clearance. Target PPFD is 100 µmol/m²/s (balanced for sulforaphane and vitamins). Default photoperiod is 14 hours on / 10 hours off. Each LED channel is independently software-controlled by the ESP32, allowing the germination blackout (days 1–2) to be enforced per-tray without physical intervention.

---

## Lighting Requirements (from design-requirements.md)

| Requirement | Value |
|---|---|
| PPFD at tray surface | 80–120 µmol/m²/s |
| Spectrum | Full-spectrum 5000–6500K white, or red (660nm) + blue (450nm) |
| Photoperiod | 14h on / 10h off (default) |
| Germination blackout | Days 0–2 per tray: LED off |
| Power supply | 12V DC |
| Max power per tray | 5W (budget); target 3W with efficient LEDs |
| Independent control | Yes — each tray has its own switched channel |

---

## Spectrum Selection

### Option A: Full-Spectrum White LED (Recommended)

**Specification: 5500–6500K colour temperature, high CRI (≥80)**

| Pros | Cons |
|---|---|
| Simpler wiring (single LED type) | Slightly less efficient than tuned red/blue |
| Low cost (standard LED strips) | Cannot tune spectrum post-build |
| Produces natural-looking plant growth | — |
| Easier to source and replace | — |

White LEDs at 6000K emit strongly in both the blue (430–480nm) and red (620–680nm) absorption peaks of chlorophyll, plus a broad midrange that supports carotenoid and anthocyanin synthesis. For microgreens harvested at day 8–10, the full spectrum is appropriate and avoids the all-red "leggy growth" phenomenon.

### Option B: Red + Blue Bichromatic

**Specification: ~660nm red + ~450nm blue, ratio 3:1 (R:B)**

| Pros | Cons |
|---|---|
| Most efficient photosynthetic activation | Produces purple/magenta light (visually unappealing) |
| Targeted spectrum | More complex driver; two LED types |
| Can tune for carotenoid (more red) or vitamin C (more blue) | — |

**Selected: Option A (full-spectrum white)** — simpler, lower cost, adequate performance, easier to source replacements. If a future revision requires spectrum tuning, Option B LED drivers can be swapped in without changing the enclosure.

---

## LED Panel Specification

| Parameter | Value |
|---|---|
| Quantity | 3 (one per tray level) |
| Format | PCB LED board, 100×100 mm (custom) OR pre-made 10×10cm LED panel |
| Voltage | 12V DC |
| Power per panel | **3W nominal** (current-limited by driver); budget for 5W |
| Current at 12V / 3W | 250 mA |
| LED type | Samsung LM301H, LM281B+, or equivalent high-efficacy LED (≥2.7 µmol/J) |
| OR (budget option) | 12V LED grow strip 60 LEDs/m, SMD 2835, 4.8W/m; cut to 60 cm, folded into 15×15cm grid |
| Colour temperature | 5000–6500K |
| Expected PPFD at 10cm | ~100–130 µmol/m²/s (measured at center; ~80 µmol/m²/s at edges) |
| Beam angle | 120° (wide flood to maximise coverage over 25×25cm) |
| Mounting clearance | **10 cm above tray surface** (adjustable ±3 cm via slotted bracket) |
| Heat dissipation | Passive; aluminium PCB or aluminium tape backing; no fan required at 3W |

### PPFD Calculation (3W, 2.7 µmol/J LEDs, 10cm distance)

```
Light output: 3W × 2.7 µmol/J = 8.1 µmol/s total
Coverage area: 25×25 cm = 625 cm² = 0.0625 m²
Average PPFD: 8.1 µmol/s / 0.0625 m² = 130 µmol/m²/s (theoretical)

Accounting for optical losses (~25%): 130 × 0.75 = ~97 µmol/m²/s

Result: ~97–100 µmol/m²/s at tray center — meets NFR-009 target. ✓
```

At 5W (budget panel): ~162 µmol/m²/s theoretical, ~122 µmol/m²/s actual — also acceptable (upper range of target).

---

## Wiring

Each LED panel connects to a relay channel on the relay module:
- **Common positive:** 12V rail → relay NO (normally open) contact → LED panel V+
- **Common negative:** LED panel V− → GND rail
- **Relay coil:** 5V signal from ESP32 GPIO via 2N2222 transistor (or relay board with optocoupler)
- **Wire gauge:** 24 AWG for LED connections (250 mA max per panel); 20 AWG for main 12V run

### Wiring Diagram (per channel)

```
12V ──── Relay NO ──── LED+
                       │
                     [LED PANEL]
                       │
GND ────────────────── LED-

ESP32 GPIO (3.3V) → Relay module IN pin (optocoupler isolated)
```

---

## Relay Module

| Parameter | Value |
|---|---|
| Type | 4-channel 5V relay module with optocoupler isolation |
| Channels used | 3 (one per LED panel) + 1 spare (for pump) |
| Input signal | 3.3V GPIO from ESP32 (active LOW or active HIGH; configurable) |
| Contact rating | 10A @ 250VAC / 10A @ 30VDC — ample for 250mA loads |
| Cost | ~$3–6 USD |
| Part number | SRD-05VDC-SL-C relay module (generic 4-channel, widely available) |

Using all 4 relay channels: 3× LED + 1× pump. This consolidates all switched 12V loads onto a single relay board.

---

## Photoperiod Schedule

| Phase | Duration | Default time window |
|---|---|---|
| Lights ON | 14 hours | 06:00 – 20:00 (configurable) |
| Lights OFF | 10 hours | 20:00 – 06:00 |
| Germination override | Days 1–2 per tray | LED suppressed regardless of time |

**Why 14 hours:**
- 12h minimum for adequate DLI (Daily Light Integral) at 100 µmol/m²/s
- 16h maximum studied for microgreens; diminishing returns above 14h
- 14h × 100 µmol/m²/s = DLI of 5.04 mol/m²/day — within the optimal 4–8 mol/m²/day range for brassica microgreens
- Saves ~30% lighting power vs 16h photoperiod without meaningful yield loss

**Low-power mode option (configurable in firmware):** 12h photoperiod reduces daily lighting energy from 126Wh to 108Wh — useful in marginal solar conditions.

---

## Power Calculations

| Configuration | Peak lighting power | Daily energy |
|---|---:|---:|
| 3× 3W panels, 14h | 9 W | 126 Wh |
| 3× 5W panels, 14h | 15 W | 210 Wh |
| 3× 3W panels, 12h (low-power mode) | 9 W | 108 Wh |

**Design basis: 3× 3W = 9W peak, 126 Wh/day lighting energy.**

---

## LED Panel Options (Procurement)

### Option 1: Pre-made 12V LED Grow Panel (easiest)
- Search: "12V 10W LED grow panel 100×100mm" or "12V 5W LED grow light board"
- Current-limit to 3W by adding series resistor or adjustable LED driver
- Cost: $5–12 per panel on AliExpress
- Delivery: 2–4 weeks from China, or available on Amazon ($10–20)

### Option 2: DIY Strip on 3D-Printed Backing (most customizable)
- 12V 2835 LED strip, 60 LEDs/m, 4.8W/m, 6000K
- Cut 4× 15cm strips (= 60cm total, ~2.88W)
- Mount on 3D-printed 100×100mm sled with reflective tape backing
- Seal with clear conformal coating for moisture protection
- Cost: $3–5 per panel

### Option 3: Samsung LM301H PCB (highest efficiency, custom)
- Order custom PCB from JLCPCB ($5 for 5 boards)
- Hand-solder 9× LM301H LEDs in 3S3P configuration (3W at 12V)
- Requires basic PCB design (KiCad or EasyEDA)
- Cost: $8–15 per panel; highest quality
- **Recommended for final production version**

**Phase 03 will finalize LED panel selection. Option 1 recommended for prototype.**

---

## Thermal Management

At 3W per panel, heat dissipation is minimal:
- LED efficiency: ~40–50% → ~1.5W heat per panel
- No forced cooling required at this power level
- Aluminium-backed PCB (standard for LED strips) sufficient
- Enclosure provides passive convection

Monitor that growing chamber temperature stays between **18–24°C** for optimal broccoli growth. If ambient temperature exceeds 30°C, consider adding a small 5V computer fan ($2) for forced convection. This is not required for typical room-temperature or vehicle operation.

---

## Nutrient Impact of Light Settings

From research ([nutritional-profile.md](../01-research/nutritional-profile.md)):
- **100–150 µmol/m²/s:** Higher chlorophyll, carotenoids, anthocyanins
- **50–75 µmol/m²/s:** Higher vitamin C and total phenolics

The 100 µmol/m²/s target balances both. If the user desires maximum vitamin C, reduce LED drive current by ~40% (add resistor or use PWM dimming via ESP32) — no hardware change required.

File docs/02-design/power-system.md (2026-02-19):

# Power System Design

**Phase:** 02 Design
**Status:** Complete
**Last Updated:** 2026-02-17

---

## Summary

The device operates on 12V DC primary power, sourced from a solar panel + LiFePO4 battery system (off-grid / vehicle), or a standard 12V DC mains adapter (home use). The system draws an average of 5.6W and a peak of 14.5W. A 40W solar panel with a 20Ah LiFePO4 battery provides adequate power in regions with ≥4 peak sun hours/day. In a vehicle, the 12V vehicle electrical system serves as the primary supply. All logic runs at 3.3V supplied by an on-board regulator from the 12V rail.

---

## Power Requirements (from design-requirements.md)

| Parameter | Value |
|---|---|
| Primary supply voltage | 12V DC |
| Average power draw | 5.6W (134 Wh/day) |
| Peak power draw | 14.5W |
| Average current (12V) | 0.47A |
| Peak current (12V) | 1.21A |
| Input connector | 5.5/2.1mm barrel jack |

---

## Load Analysis

| Load | Component | Peak Power | Duty | Avg Power |
|---|---|---|---|---|
| Lighting | 3× LED panel (3W each) | 9.0 W | 14/24 = 58% | 5.25 W |
| Pump | 12V peristaltic | 5.0 W | 6min/day = 0.4% | 0.02 W |
| MCU | ESP32 (active) | 0.35 W | ~70% active | 0.25 W |
| RTC | DS3231 | 0.01 W | 100% | 0.01 W |
| Sensors | Water level | 0.1 W | 50% polling | 0.05 W |
| Display | 0.96" OLED (optional) | 0.05 W | 25% | 0.01 W |
| Status LEDs | 4× 3mm LED | 0.04 W | varies | 0.02 W |
| **Total** | | **14.55 W peak** | | **5.61 W avg** |

**Daily energy: 5.61W × 24h = 134.6 Wh/day**

---

## Power Supply Options

### Option 1: Solar + Battery (Primary Off-Grid / Vehicle Option)

#### Solar Panel
| Parameter | Value |
|---|---|
| Rated power | **40W** (minimum); 50W recommended |
| Type | Monocrystalline, 12V nominal |
| Open circuit voltage (Voc) | ~21V |
| Max power voltage (Vmp) | ~17V |
| Short circuit current (Isc) | ~2.5A (40W) |
| Size (approximate) | ~40W: 530×355mm; fits on vehicle roof rack |
| Cost | $25–45 USD |

**Energy balance check:**
```
Generation (40W, 4 peak sun hours, 85% efficiency):
  40W × 4h × 0.85 = 136 Wh/day

Daily consumption: 135 Wh/day

Net: +1 Wh/day (break-even at 4 peak sun hours)
```
→ 40W panel achieves energy balance in 4 peak sun hours (conservative US average).
→ In 3 peak sun hours: 40 × 3 × 0.85 = 102Wh/day — draws 33Wh/day from battery.
→ In 5 peak sun hours: 40 × 5 × 0.85 = 170Wh/day — surplus 35Wh/day charges battery.

**Recommendation: 50W panel** for comfortable positive energy balance in all but extreme low-sun conditions ($35–55).

#### MPPT Solar Charge Controller
| Parameter | Value |
|---|---|
| Type | MPPT (Maximum Power Point Tracking) — 8–15% more efficient than PWM |
| Rating | 10A, 12V/24V auto |
| Input voltage range | Up to 50V input — suitable for 40W panel |
| Output | 12V to battery |
| Protection | Overcharge, overdischarge, short circuit, reverse polarity |
| Cost | $12–25 USD |
| Example | Epever 10A MPPT, Victron SmartSolar 75/10, generic 10A MPPT |

#### Battery
| Parameter | Value |
|---|---|
| Chemistry | **LiFePO4** (lithium iron phosphate) |
| Voltage | 12V (4S LiFePO4: 4 × 3.2V = 12.8V nominal) |
| Capacity | **20Ah** |
| Usable energy | 20Ah × 12V × 0.8 (80% DoD) = **192 Wh** |
| Autonomy (no solar) | 192 Wh / 5.61W = **34 hours** |
| Autonomy (30W solar, 3h sun) | Deficit = 135 – 102 = 33 Wh/day; battery lasts 192/33 = **5.8 days** |
| Charge cycles | >2000 cycles to 80% capacity |
| Weight | ~2.5 kg |
| BMS | Built-in (required) |
| Cost | $35–70 USD |
| Form factor | Standard 20Ah LiFePO4 12V box battery |

**Why LiFePO4 over lead-acid:**
- Much lighter (2.5 kg vs. ~7 kg for equivalent lead-acid)
- Tolerates 80% depth of discharge vs. 50% for lead-acid
- Stable chemistry (no off-gassing; safe in enclosed vehicle)
- Longer cycle life

**Why LiFePO4 over lithium polymer (LiPo):**
- Safer in high-temperature vehicle environments
- No fire risk from over-discharge or puncture
- BMS is simpler/cheaper

### Option 2: Vehicle 12V Supply (Mobile Use, No Solar Panel Needed)

In a vehicle, the device connects directly to the vehicle's 12V electrical system:
- Via cigarette lighter / 12V accessory socket (typically fused at 10–20A — ample)
- Or direct to battery via inline 5A fuse

| Consideration | Detail |
|---|---|
| Voltage range | Vehicle 12V varies 11.5–14.8V (charging) — device must tolerate this |
| Regulator requirement | Yes — use a buck converter to regulate to stable 12V for LEDs |
| Connection | Cigarette lighter plug (5A rated) or Anderson Powerpole connector |
| Running while parked | Draws 0.47A avg; OK for vehicle battery if vehicle runs daily |
| Risk | Avoid fully depleting vehicle battery if parked >2 days without running |
| Mitigation | Low-voltage cutoff relay at 11.5V (protects vehicle battery) |

### Option 3: 12V Mains Adapter (Home Use)

Simplest option for stationary home use:

| Parameter | Value |
|---|---|
| Adapter spec | 12V DC, 2A (24W) — provides margin over 14.5W peak |
| Connector | 5.5/2.1mm barrel (positive centre) |
| Cost | $8–15 USD |
| Protection | Regulated output; short-circuit protected |

This option requires no battery, no MPPT controller, and no solar panel. Total home-use BOM is significantly lower.

---

## On-Board Power Distribution

### Voltage Rails

| Rail | Voltage | Source | Loads |
|---|---|---|---|
| V_BAT | 12V (unregulated, 11–14.8V) | Battery / vehicle / adapter | LED panels, pump relay |
| V_12 | 12V regulated | Buck converter (if needed) | Relay module coil |
| V_5 | 5V regulated | LM7805 or MP1584 buck module | ESP32 VIN, relay logic |
| V_3V3 | 3.3V | ESP32 internal LDO | MCU, sensors, OLED |

**Preferred regulator: MP1584EN-based buck module** (wide input 4–28V, adjustable output, 3A max, ~$1–2 USD). More efficient and lower heat than LM7805 linear regulator.

### Power Input Stage

```
12V Input (barrel jack)
      │
   [Reverse polarity protection — P-channel MOSFET or Schottky diode]
      │
   [5A Inline fuse]
      │
   [12V Bus]
   /         \
[LED relays]  [Buck converter → 5V → ESP32]
[Pump relay]
```

**Inline fuse:** 5A polyblade automotive fuse in fuse holder — protects wiring from short circuits.

**Reverse polarity protection:** Required for solar/vehicle use where polarity errors are possible.

---

## Protection Features

| Protection | Implementation |
|---|---|
| Reverse polarity | P-channel MOSFET gate circuit or series Schottky diode |
| Overcurrent | 5A inline fuse |
| LED short circuit | LED panels individually fused or current-limited via driver |
| Low battery cutoff | MPPT controller built-in + optional low-voltage relay at 11.5V |
| Overtemperature | ESP32 NTC monitoring (optional); enclosure passive cooling sufficient at 5.6W avg |
| Water ingress into electronics | Electronics bay physically separated from growing/water zone by PETG wall + gasket |

---

## Power System BOM Estimate

### Off-Grid Solar Configuration (Full)

| Item | Qty | Unit Cost | Total |
|---|-----|---|---|
| 40W or 50W monocrystalline solar panel | 1 | $30–55 | $30–55 |
| 10A MPPT solar charge controller | 1 | $15–25 | $15–25 |
| 20Ah LiFePO4 12V battery | 1 | $40–70 | $40–70 |
| Solar panel cable + connectors (MC4) | 1 set | $5–10 | $5–10 |
| Anderson Powerpole connectors | 1 set | $3–5 | $3–5 |
| **Solar subtotal** | | | **$93–165** |

### On-Device Electronics

| Item | Qty | Unit Cost | Total |
|---|-----|---|---|
| 5.5/2.1mm barrel jack (panel mount) | 1 | $1 | $1 |
| MP1584EN buck converter module (12V→5V) | 1 | $1–2 | $1–2 |
| 5A blade fuse + holder | 1 | $1–2 | $1–2 |
| P-channel MOSFET (reverse polarity) | 1 | $0.50 | $0.50 |
| Wiring (20 AWG hookup wire, 3m) | 1 | $3–5 | $3–5 |
| JST-XH connectors (power distribution) | 1 set | $2–4 | $2–4 |
| **On-device power hardware** | | | **~$8–15** |

### Mains-Only Alternative

| Item | Qty | Unit Cost | Total |
|---|-----|---|---|
| 12V 2A mains adapter | 1 | $8–15 | $8–15 |
| **Mains subtotal** | | | **$8–15** |

---

## Vehicle Installation Notes

1. Connect via cigarette lighter with an inline 5A fuse or direct to battery via Anderson Powerpole.
2. Ensure the 12V accessory socket is switched off when ignition is off (most modern vehicles) OR use the low-voltage cutoff relay to prevent battery drain.
3. Route cable away from heat sources (exhaust, engine bay).
4. Secure the device with a friction mat or Velcro for vehicle stability.
5. The device can run while driving; pump and light cycles continue normally while vehicle is in motion.

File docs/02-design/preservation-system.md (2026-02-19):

# Preservation System

**Phase:** 02 Design
**Status:** Complete — No On-Device Preservation Hardware Required
**Last Updated:** 2026-02-17

---

## Summary

The device has no on-board preservation subsystem. Per DECISION-004, the device outputs fresh-cut microgreens. Post-harvest preservation is handled by the user using a standard kitchen refrigerator (primary) and standard kitchen freezer (secondary, and surprisingly superior for sulforaphane bioavailability). This document defines the user workflow and design features that support the preservation process.

---

## Why No On-Device Preservation

From DECISION-004 (established in Phase 01 research):

1. **Fresh refrigeration** preserves 100% of myrosinase activity and sulforaphane bioavailability — no device needed beyond the user's refrigerator.

2. **Raw home freezing** (FINDING-011) actually *increases* sulforaphane yield by up to 3.1× vs. unfrozen — and requires only the user's standard kitchen freezer. The device does not need to replicate this.

3. The two remaining preservation methods evaluated (freeze-drying, low-temp dehydration) are either too expensive ($2,000–$5,000 for a home freeze-dryer) or add significant device complexity for modest gain when raw freezing is freely available and superior.

4. Adding a refrigeration or dehydration module would increase cost, power draw, enclosure size, and mechanical complexity — all contrary to the design goals.

**Conclusion: The preservation system is the user's refrigerator + freezer. The device's job is to produce and present fresh-cut greens efficiently.**

---

## Device Features That Support Preservation

While no preservation hardware is included, the device design incorporates several features to streamline the post-harvest workflow:

### 1. Harvest Ready Indicator

The ESP32 tracks the seeding day for each tray. On days 8–10, a harvest-ready LED illuminates for that tray level. This prevents over-maturation (which reduces GRN concentration) and ensures the user harvests at peak sulforaphane content.

### 2. Dry-Before-Harvest Protocol

The firmware suppresses the final watering event before the scheduled harvest window. Specifically, the watering event on the morning of day 8 (the first day of the harvest window) is withheld for the target tray. Dry microgreens:
- Store longer in the refrigerator (surface moisture promotes mold)
- Are easier to cut cleanly
- Freeze without clumping

This is implemented as a software flag; no hardware is required.

### 3. Portion Marking System

The enclosure top cap includes a small compartment (30 mL volume) for storing:
- A permanent marker for dating freezer bags
- Small zip-lock bags (30g portions) for the freezer
- Optionally, a luggage scale label / reference card

This is a minor 3D-printed feature with no electronics.

---

## Post-Harvest User Workflow

### For Fresh Consumption (Days 1–3 after harvest)

1. Harvest the target tray when harvest LED illuminates
2. Cut greens at coir level with scissors
3. Place in airtight container lined with paper towel
4. Refrigerate immediately at 2–5°C
5. Consume within 5–7 days — blend into morning smoothie raw

### For Frozen Storage (Surplus from each harvest event)

1. Harvest tray (~90–130g)
2. Take 30–60g to refrigerator for immediate use
3. Remaining 60–100g: portion into 30g lots
4. Place each portion in a small zip-lock bag; press out air, seal
5. Label with date using permanent marker
6. Lay bags flat in freezer at −20°C for minimum 24 hours before use
7. Use within 3–6 months — blend directly from frozen (do NOT thaw)
8. Add to blender with fruit; blend immediately; drink within 20 minutes

**This protocol maximizes sulforaphane — the frozen-then-blended approach can yield up to 3× more sulforaphane than consuming fresh-unfrozen greens.**

---

## Shelf Life Reference Card

This card should be printed and placed inside the enclosure top cap for user reference:

```
┌────────────────────────────────────────────────────────┐
│          MICROGREEN STORAGE GUIDE                      │
│                                                        │
│  FRESH (refrigerator 2–5°C)                           │
│  └─ Shelf life: 5–7 days                              │
│  └─ Sulforaphane: MAXIMUM                             │
│  └─ Use: raw in smoothie or salad                     │
│                                                        │
│  FROZEN (−20°C, raw, unblanched)                      │
│  └─ Shelf life: 3–6 months                            │
│  └─ Sulforaphane: UP TO 3× MORE than fresh            │
│  └─ Use: blend directly from frozen — do NOT thaw     │
│                                                        │
│  NEVER: cook, blanch before freezing, or discard      │
│         thaw liquid                                    │
└────────────────────────────────────────────────────────┘
```

---

## Quantities at Each Harvest Event

| Scenario | Tray yield | To refrigerator | To freezer |
|---|---|---|---|
| Conservative (80g/tray) | 80g | 30g (3 days) | 50g (50÷30 = 1.6 → 1 bag) |
| Expected (110g/tray) | 110g | 30g (3 days) | 80g (2–3 bags of 30g) |
| High yield (130g/tray) | 130g | 60g (5 days) | 70g (2 bags of 30g) |

At the expected yield of 110g per harvest every 3 days:
- **2–3 frozen 30g portions** are produced per harvest event
- After 4 cycles, the user has 8–12 frozen doses in reserve — a 24–36 day backup supply

---

## Design Boundary Statement

| System boundary | In scope | Out of scope |
|---|---|---|
| Growing and harvesting | ✅ | — |
| Harvest-ready notification | ✅ | — |
| Dry-harvest protocol (last watering withheld) | ✅ | — |
| Portion bag storage compartment | ✅ | — |
| Refrigeration hardware | ❌ (user's fridge) | — |
| Freezer hardware | ❌ (user's freezer) | — |
| Freeze-drying | ❌ (out of scope) | — |
| Dehydration | ❌ (user's dehydrator, optional) | — |

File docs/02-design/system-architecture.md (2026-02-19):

# System Architecture

**Phase:** 02 Design
**Status:** Complete
**Last Updated:** 2026-02-17

---

## Overview

The microgreen box is a self-contained, automated vertical growing device with 3 tray levels. It is powered by 12V DC (solar/battery or wall adapter), controlled by an ESP32 microcontroller, and produces ~30 g/day of fresh broccoli microgreens via a staggered 3-tray rotation. All water is contained in sealed reservoirs. There is no on-device food processing — the device outputs fresh cut greens.

---

## Subsystem Map

| Subsystem | Responsibility | Document |
|---|---|---|
| Growing System | Trays, coir medium, seed rotation schedule | [growing-system.md](growing-system.md) |
| Lighting System | Per-tray LED panels, 14h photoperiod, germination blackout | [lighting-system.md](lighting-system.md) |
| Watering System | Sealed 2L reservoir, peristaltic pump, top-drip delivery | [watering-system.md](watering-system.md) |
| Power System | 12V DC input, MPPT solar controller, LiFePO4 battery | [power-system.md](power-system.md) |
| Preservation System | N/A (device scope: fresh output only); user workflow documented | [preservation-system.md](preservation-system.md) |
| Enclosure | PETG 3D-printed column, sealed, vehicle-stable | [enclosure-design.md](enclosure-design.md) |
| Control System | ESP32, firmware, sensors, scheduling | docs/04-software/ |

---

## System Block Diagram

```
┌─────────────────────────────────────────────────────────────┐
│                     POWER SYSTEM (12V)                      │
│  [Solar Panel] → [MPPT Controller] → [LiFePO4 Battery]     │
│                           ↓                                  │
│                    [12V Power Rail]                          │
│                    [5V Regulator]                            │
└─────────────────────┬───────────────────────────────────────┘
                      │ 12V / 5V
                      ▼
┌─────────────────────────────────────────────────────────────┐
│                   CONTROL SYSTEM (ESP32)                    │
│                                                             │
│  ┌──────────────┐   ┌──────────────┐   ┌────────────────┐  │
│  │ RTC (DS3231) │   │ Water Level  │   │ Day Counters   │  │
│  │ Timekeeping  │   │ Sensor (ADC) │   │ (per tray)     │  │
│  └──────┬───────┘   └──────┬───────┘   └────────┬───────┘  │
│         └──────────────────┴────────────────────┘          │
│                           │ Decisions                        │
│                           ▼                                  │
│  ┌─────────────┐   ┌─────────────┐   ┌──────────────────┐  │
│  │ LED Relay   │   │ Pump Relay  │   │ Status LEDs /    │  │
│  │ (3 channels)│   │ (1 channel) │   │ OLED Display     │  │
│  └──────┬──────┘   └──────┬──────┘   └──────────────────┘  │
└─────────┼────────────────┼────────────────────────────────  ┘
          │ 12V switched   │ 12V switched
          ▼                ▼
┌─────────────────┐  ┌──────────────────────────────────────┐
│  LIGHTING       │  │         WATERING SYSTEM              │
│  SYSTEM         │  │                                      │
│                 │  │  [Sealed 2L Reservoir]               │
│  [LED Panel A]  │  │         ↓                            │
│  [LED Panel B]  │  │  [Peristaltic Pump (12V)]            │
│  [LED Panel C]  │  │         ↓                            │
│                 │  │  [Manifold → Tray A / B / C drip]   │
└────────┬────────┘  └────────────────────┬─────────────────┘
         │                               │
         ▼                               ▼
┌─────────────────────────────────────────────────────────────┐
│                    GROWING SYSTEM                           │
│                                                             │
│  ┌────────────────────────────────────────────────────┐    │
│  │  TRAY LEVEL A (top)                                │    │
│  │  [LED Panel A above] [Coir tray 25×25cm]          │    │
│  │  [Sub-tray sealed water reservoir below]           │    │
│  └────────────────────────────────────────────────────┘    │
│  ┌────────────────────────────────────────────────────┐    │
│  │  TRAY LEVEL B (middle)                             │    │
│  │  [LED Panel B above] [Coir tray 25×25cm]          │    │
│  │  [Sub-tray sealed water reservoir below]           │    │
│  └────────────────────────────────────────────────────┘    │
│  ┌────────────────────────────────────────────────────┐    │
│  │  TRAY LEVEL C (bottom)                             │    │
│  │  [LED Panel C above] [Coir tray 25×25cm]          │    │
│  │  [Sub-tray sealed water reservoir below]           │    │
│  └────────────────────────────────────────────────────┘    │
│                                                             │
│  [Main 2L Reservoir] [Waste Collection Chamber] [Base]     │
└─────────────────────────────────────────────────────────────┘
```

---

## Subsystem Interfaces

| Interface | From | To | Signal / Medium | Specification |
|---|---|----|---|---|
| 12V power | Power system | LED relays, pump relay | 12V DC wire, JST connectors | ≥2A continuous |
| 5V power | 5V regulator | ESP32, sensors, OLED | 5V DC regulated | ≥1A |
| LED control | ESP32 GPIO | LED relay module (3-ch) | 3.3V digital signal | GPIO 12, 13, 14 (suggested) |
| Pump control | ESP32 GPIO | Pump relay | 3.3V digital signal | GPIO 15 (suggested) |
| Water level | Water level sensor | ESP32 ADC | Analog 0–3.3V or I2C digital | ADC pin or I2C |
| Time reference | DS3231 RTC | ESP32 | I2C (SDA/SCL) | 400kHz |
| Status output | ESP32 GPIO | Status LEDs (×4) | 3.3V via 330Ω resistor | GPIO 16–19 |
| Optional display | ESP32 I2C | 0.96" OLED | I2C (shared bus with RTC) | 400kHz |
| Drip tubing | Pump outlet | Per-tray drip emitters | 6mm OD silicone food-grade tubing | 3 branches via manifold |
| Drain / overflow | Growing sub-tray | Waste chamber | 6mm silicone tubing via gravity | Sealed fitting |

---

## Controller Selection: ESP32

**Selected:** ESP32 (e.g., ESP32-WROOM-32 dev board)

| Feature | Value | Relevance |
|---|---|---|
| Cost | ~$4–8 USD | Low-cost target |
| Supply voltage | 3.3V logic; 5V USB/VIN input | Compatible with 5V regulator |
| GPIO | 34 usable pins | Ample for LED relay ×3, pump relay, sensors, OLED, RTC |
| I2C / SPI | Yes (hardware) | RTC (DS3231), OLED display |
| ADC | 12-bit, 18 channels | Water level analog sensor |
| WiFi | 802.11 b/g/n built-in | Optional remote monitoring / OTA update |
| Deep sleep | 10 µA sleep current | Battery preservation when no active scheduling |
| IDE | Arduino IDE + ESP32 board package | Widely supported, low barrier |
| Flash | 4MB | Ample for firmware + config storage |
| Programming | USB-UART via boot button | Standard |

**Alternatives considered:**
- Arduino Nano: lower cost but no WiFi, less RAM, harder to add future features
- Raspberry Pi Zero W: more capable but 500mA at 5V (power hungry), Linux boot time adds complexity
- ATtiny85: too limited for 3-channel lighting + pump + RTC + sensors + display

---

## Firmware Responsibilities

| Function | Description |
|---|---|
| Day counter (per tray) | Track seeding date per tray; trigger blackout (days 0–2) and harvest alert (days 7–10) |
| Light scheduler | Enable/disable each LED channel on daily on/off schedule, respecting per-tray blackout |
| Watering scheduler | Trigger pump for configurable duration, 2× daily |
| Water level monitor | Poll sensor; activate low-water LED/buzzer if below threshold |
| Status display | Drive OLED or LEDs with current tray status, day counts, reservoir level |
| Configuration | Read schedule parameters from flash or config file; adjustable without recompiling |
| WiFi (optional) | Serve status page on local network; allow OTA firmware updates |

---

## Physical Layout (Vertical Column)

```
  ┌──────────────────────────┐  ← Top cap / seed storage compartment
  │   [LED Panel A]          │  ← Level A light (facing down)
  │   [Tray A — coir + seed] │  ← Growing tray (removable)
  │   [Sub-tray A — sealed]  │  ← Water retention / drainage
  ├──────────────────────────┤
  │   [LED Panel B]          │  ← Level B light
  │   [Tray B — coir + seed] │
  │   [Sub-tray B — sealed]  │
  ├──────────────────────────┤
  │   [LED Panel C]          │  ← Level C light
  │   [Tray C — coir + seed] │
  │   [Sub-tray C — sealed]  │
  ├──────────────────────────┤
  │   [Main Water Reservoir] │  ← 2L sealed; fill from top port
  │   [Waste Chamber]        │  ← Collects drain overflow
  │   [Electronics bay]      │  ← ESP32, relays, power regulator, RTC
  └──────────────────────────┘  ← Base with anti-slip feet / vehicle mount points
```

Total height (3-tray, base, top): ~85 cm
Footprint: 30 × 30 cm

---

## Scalability

Each "tray module" (LED + tray + sub-tray) is mechanically identical and stackable. To scale from 3 to 4 trays for 60 g/day output:

1. Print and add one additional tray module section (enclosure ring + LED bracket + tray + sub-tray)
2. Add one additional LED relay channel to the MCU (or use I2C GPIO expander)
3. Extend drip tubing from manifold to new tray
4. Update firmware configuration (tray count = 4)
5. No changes to reservoir, power system, or electronics bay needed (within power budget)

---

## Data Flow

```
RTC → ESP32 (time of day)
    ↓
Lighting Scheduler:
  If (hour >= on_time AND hour < off_time AND tray_day >= 3):
    Enable LED channel for tray
  Else:
    Disable LED channel

Watering Scheduler:
  If (hour == water_time_1 OR hour == water_time_2):
    Run pump for pump_duration_seconds

Water Level Monitor (every 30 min):
  Read ADC/sensor
  If level < threshold:
    Set low_water_flag = true
    Activate warning LED

Tray Day Counter (daily at midnight):
  Increment tray_A_day, tray_B_day, tray_C_day
  If tray_N_day >= harvest_day_threshold:
    Activate harvest_ready LED for tray N
  If tray_N_day > max_day:
    Alert (overdue harvest)
```

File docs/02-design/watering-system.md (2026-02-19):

# Watering System Design

**Phase:** 02 Design
**Status:** Complete
**Last Updated:** 2026-02-17

---

## Summary

Water is delivered via a 12V peristaltic pump drawing from a sealed 2-liter reservoir at the base of the unit. The pump runs twice daily, delivering approximately 25 mL per tray per event via individual top-drip emitters. Excess water drains through the growing tray into the sealed sub-tray, and overflows to a sealed waste chamber. There are no open water surfaces — the system is fully sealed and vehicle-safe.

---

## Water System Requirements

| Requirement | Value | Source |
|---|---|---|
| Water containment | Fully sealed — no open surfaces | FR-006, claude.md (vehicle) |
| Daily water volume | ~50–150 mL total (all trays) | production-targets.md (USDA data) |
| Reservoir capacity | **2 L minimum** (targets 7+ days unattended) | NFR-001 |
| Low-water alert | Visual LED indicator | FR-009 |
| Power supply | 12V DC | FR-003 |
| Vehicle stability | Sealed reservoir; all fittings sealed or valved | FR-006 |
| Noise | Pump ≤ 50 dB at 1m | NFR-004 |

---

## Water Delivery Architecture

```
[2L Sealed Reservoir]
         │
   [Peristaltic Pump — 12V]
         │
   [4-way silicone manifold]
    /     │     \
[Tray A] [Tray B] [Tray C]
(drip)   (drip)   (drip)
    ↓        ↓        ↓
[Sub-tray A] [Sub-tray B] [Sub-tray C]
(sealed)     (sealed)     (sealed)
    ↓           ↓           ↓
[Overflow tubing to Waste Chamber]
```

The pump runs for a timed duration; no flow-rate sensors are needed. Timing is calibrated during setup to deliver the correct volume. All tubing runs inside the enclosure.

---

## Watering Method: Top-Drip

**Selected method:** Top-drip from above, through coir, into sealed sub-tray.

| Method | Suitability for vehicle | Notes |
|---|---|---|
| Top-drip | ★★★★★ | Enclosed drip path; no standing water at surface |
| Bottom flood/drain | ★★☆☆☆ | Open water in sub-tray sloshes in vehicle |
| Misting / fogging | ★★★☆☆ | Harder to contain; more complex plumbing |
| Wicking from below | ★★★★☆ | Passive, no pump needed, but harder to control delivery precisely |

**Rationale:** Top-drip is the most vehicle-compatible active watering method. Water exits the drip emitter into the coir, which absorbs it. No standing water remains at the coir surface. Sub-trays catch drain-through water in a sealed chamber. If the vehicle moves, water stays in sealed sub-trays and waste chamber — no spill risk.

---

## Pump Selection

**Selected: 12V DC Peristaltic Pump**

| Parameter | Value |
|---|---|
| Type | Peristaltic (roller type) |
| Voltage | 12V DC |
| Flow rate | 40–100 mL/min (adjustable by tubing ID and motor speed) |
| Power consumption | 3–5W during operation |
| Tubing ID | 4–6mm silicone (food-grade) |
| Dry-run safe | Yes — peristaltic pumps can run dry without damage |
| Run duration per watering event | ~20–40 seconds (to deliver 25 mL per tray; 75 mL total at 3 trays) |
| Noise level | ~40–50 dB at 30cm; quiet during brief cycles |
| Mounting | Any orientation (peristaltic pumps work inverted) — important for vehicle |
| Cost | $8–18 USD (AliExpress/Amazon) |
| Example parts | Kamoer F01A, generic 12V peristaltic pump, widely available |

**Why peristaltic over submersible:**
- No priming needed — self-priming
- Works in any orientation (critical for vehicle tilting)
- Food-safe silicone tubing is the only water-contact surface
- No risk of running reservoir dry and burning out motor
- Precise timing = precise volume delivery

---

## Reservoir Design

| Parameter | Value |
|---|---|
| Capacity | **2.0 L** |
| Material | PETG (3D-printed) or food-grade HDPE container |
| Form | Rectangular, fits in enclosure base: ~200×150×70mm |
| Fill port | Top-access screw cap (O-ring sealed) |
| Outlet fitting | Ø6mm barbed fitting, silicone sealed, at base of reservoir |
| Water level sensor port | Ø10mm port at side, for sensor probe or sight glass |
| Vent | 0.5mm pin hole in cap + hydrophobic PTFE vent membrane (prevents pressure lock, excludes water) |
| Vehicle stability | Secured in enclosure base with retaining brackets; sealed cap |

### Reservoir Autonomy

```
Daily water use: ~150 mL/day (3 trays × 2 events × 25 mL)
Reservoir capacity: 2,000 mL
Autonomy: 2,000 / 150 = ~13.3 days
```

**A 2L reservoir provides >13 days of autonomous operation** — well exceeding the 7-day NFR target. In practice, some water evaporates through the growing medium, so real-world autonomy is approximately **10–14 days**.

---

## Watering Schedule

| Parameter | Value | Notes |
|---|---|---|
| Events per day | **2** | Morning and evening |
| Default times | 07:00 and 19:00 | Configurable in firmware |
| Duration per event | 20–40 sec (calibrate at setup) | Delivers ~25 mL per tray |
| Volume per event (3 trays) | ~75 mL | Pump runs once; manifold splits to 3 trays |
| Germination adjustment | No change needed | Coir absorbs same amount; blackout only affects light |
| Harvest day adjustment | Withhold last watering before harvest | Dry greens are easier to cut and store; reduces mold risk |

### Calibration Procedure

At initial setup, calibrate pump duration to deliver 25 mL per tray:
1. Disconnect manifold; run pump into measuring cup for 30 seconds
2. Measure volume; calculate mL/second
3. Set pump_duration = 25 mL × 3 trays / (mL/sec flow rate)
4. Record in firmware configuration

Recalibrate if tubing or pump is replaced.

---

## Water Distribution Manifold

| Parameter | Value |
|---|---|
| Type | 1-to-3 splitter (Y + T fittings, or 3D-printed manifold block) |
| Tubing | 4mm ID × 6mm OD food-grade silicone |
| Drip emitters | 1 emitter per tray; Ø2mm drip hole or gravity emitter |
| Emitter flow (gravity at 25cm head) | ~2–5 mL/min — pump creates positive pressure; flow rate controlled by pump |
| Tubing length | ~50 cm per run (top tray) to ~10 cm (bottom tray) |
| Routing | Internal to enclosure column; secured with printed cable clips |

**Vehicle note:** All tubing is firmly clipped to the interior wall of the enclosure. No loose tubes that can dislodge during motion.

---

## Drainage and Waste System

### Sub-Tray to Waste Path

Each sub-tray has an overflow port at 25mm from the base (25×25cm = 625cm²; 25mm depth = 156mL capacity before overflow). Under normal operation, the sub-tray retains 5–15mm of water which wicks back up into the coir — no overflow expected unless the drip emitter is blocked or over-configured. Overflow fitting ensures sub-tray never exceeds 25mm.

### Waste Chamber

| Parameter | Value |
|---|---|
| Location | Adjacent to main reservoir in the base |
| Capacity | 500 mL |
| Material | PETG (3D-printed) |
| Drain interval | User empties as needed; expected <50 mL/week under normal operation |
| Access | Sealed cap for pouring out; or barbed drain fitting for tubing |

---

## Water Level Sensor

| Parameter | Value |
|---|---|
| Type | Float switch (simple, reliable) OR capacitive liquid level sensor (no moving parts, preferred) |
| Mount | On the side wall of the 2L reservoir |
| Trigger level | Activates at ~200 mL remaining (10% capacity = ~1 day reserve) |
| Output | Digital signal to ESP32 GPIO |
| Alert | Red/yellow LED on device; optional WiFi push notification |
| Cost | $1–5 (float switch) or $3–8 (capacitive) |

**Preferred: capacitive or optical water level sensor** (no moving parts, vehicle-stable — float switches can give false readings under motion).

---

## Vehicle-Specific Design Features

| Feature | Design solution |
|---|---|
| Reservoir tipping | Sealed cap + O-ring; no open fill port during operation |
| Tubing dislodgement | Barbed fittings + zip-tie clips; tubing runs inside column |
| Sub-tray spillage | Deep sub-tray walls (40mm); sealed overflow to waste chamber |
| Pump orientation | Peristaltic works in any orientation; mounted at base for low CG |
| Condensation | PETG interior; absorbed by coir; no drip paths to electronics |
| Electronics isolation | Electronics bay sealed from growing/water zones by PETG wall with gasket |

---

## Watering System BOM Estimate

| Item | Qty | Unit Cost | Total |
|---|-----|---|---|
| 12V peristaltic pump | 1 | $8–18 | $8–18 |
| Silicone tubing 4mm ID, 6mm OD, 2m | 1 | $3–6 | $3–6 |
| 3-way manifold fitting (or 3D-printed) | 1 | $1–3 | $1–3 |
| Drip emitters (2mm Ø) | 3 | $0.50 | $1.50 |
| Barbed fittings (Ø6mm) | 5 | $0.50 | $2.50 |
| Capacitive water level sensor | 1 | $3–8 | $3–8 |
| PETG filament (reservoir + waste chamber) | ~400g | $0.025/g | $10 |
| O-ring kit (seals) | 1 | $3–5 | $3–5 |
| **Watering system total** | | | **~$32–54** |

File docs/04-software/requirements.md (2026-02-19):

# Firmware Configuration Guide

**Phase:** 04 Software
**Status:** Complete
**Last Updated:** 2026-02-18
**Config file:** `software/firmware/microgreen_controller/config.h`

---

## Overview

All user-adjustable parameters are in `config.h`. No other files need editing for routine configuration. After changing any parameter, re-flash the firmware via Arduino IDE.

Parameters that require physical measurement (pump flow rate, sensor calibration) are marked **[Calibrate]**. All others have safe defaults that work for a standard broccoli microgreen grow.

---

## Functional Requirements Implemented

| ID | Requirement | Status | Notes |
|----|---|---|---|
| SW-001 | Control lighting on configurable schedule | ✅ | `PHOTO_ON_HOUR`, `PHOTO_OFF_HOUR` |
| SW-002 | Trigger watering pump on configurable schedule | ✅ | `WATER_HOUR_1`, `WATER_HOUR_2` |
| SW-003 | Schedules persist across power cycles | ✅ | DS3231 RTC + EEPROM |
| SW-004 | Per-tray germination blackout (lights off) | ✅ | `BLACKOUT_DAYS` |
| SW-005 | Moisture feedback: skip watering if wet | ✅ | `MOISTURE_SKIP_THRESHOLD` |
| SW-006 | Moisture feedback: top-up if still dry after event | ✅ | `MOISTURE_TOPUP_THRESHOLD` |
| SW-008 | Exclude germinating trays from watering decisions | ✅ | `GERMINATION_WATER_DAYS` — prevents damping-off |
| SW-007 | Grow-day counter per tray, persists power-off | ✅ | Seed epoch stored in EEPROM |
| SW-010 | Monitor reservoir level; alert when low | ✅ | Float switch on GPIO33 |
| SW-020 | Indicate low water via LED and buzzer | ✅ | Yellow LED + buzzer on rising edge |
| SW-021 | Indicate harvest ready per tray | ✅ | Red LEDs + one-shot buzzer beep |
| SW-022 | Power-conservative operation | ✅ | Light sleep between 60 s check cycles |
| SW-030 | Configurable light schedule | ✅ | Edit `config.h`, re-flash |
| SW-031 | Configurable water schedule | ✅ | Edit `config.h`, re-flash |

---

## Parameter Reference

### Light Schedule

#### `PHOTO_ON_HOUR` — default `6`
Hour (0–23) when grow lights turn on each day.

```c
#define PHOTO_ON_HOUR    6    // lights on at 06:00
```

Choosing a value: align with your morning routine so the lights are active when you harvest. The device harvests in the morning, so having lights on from 06:00 means fresh illuminated growth is ready at harvest time.

#### `PHOTO_OFF_HOUR` — default `20`
Hour (0–23) when grow lights turn off each day.

```c
#define PHOTO_OFF_HOUR   20   // lights off at 20:00
```

**Photoperiod = PHOTO_OFF_HOUR − PHOTO_ON_HOUR.** Default: 20 − 6 = 14 hours. Research supports 14 h/10 h for broccoli microgreens as a balance between yield and energy use. A 16 h photoperiod (e.g. OFF_HOUR = 22) increases yield marginally but uses ~15% more energy.

#### `BLACKOUT_DAYS` — default `2`
Number of days after seeding during which lights stay off regardless of photoperiod.

```c
#define BLACKOUT_DAYS    2    // days 0, 1, 2 = dark; light starts day 3
```

Broccoli seeds germinate best in darkness during days 0–2. Light exposure during germination does not harm them but offers no benefit. Day numbering: day 0 = seeded today, day 1 = next day, etc.

---

### Watering Schedule

#### `WATER_HOUR_1` — default `7`
Hour (0–23) for the first daily watering event.

```c
#define WATER_HOUR_1     7    // 07:00 morning watering
```

The pump runs once at this hour each day, subject to the moisture check (see below).

#### `WATER_HOUR_2` — default `19`
Hour (0–23) for the second daily watering event.

```c
#define WATER_HOUR_2     19   // 19:00 evening watering
```

Two events per day delivers ~150 mL/day total (75 mL per event). At 150 mL/day the 2.43 L reservoir lasts ~16 days.

#### `GERMINATION_WATER_DAYS` — default `2`
Number of days after seeding during which a tray is **excluded from moisture-driven watering decisions**.

```c
#define GERMINATION_WATER_DAYS  2
```

**Purpose:** Prevents damping-off (fungal root rot caused by *Pythium* spp.). Seeds are soaked for 4–8 hours before sowing, and the coir is already saturated on Day 0. Running the pump on a germinating tray's behalf over-saturates the medium and creates anaerobic conditions at the root zone — the primary cause of seedling damping-off.

**Behaviour:** Germinating trays (day ≤ `GERMINATION_WATER_DAYS`) are excluded from the skip and top-up moisture checks. The pump still runs when established trays need it — germinating trays receive water as a side-effect through their drip emitter. What changes is that a germinating tray cannot *trigger* a pump run on its own.

**Edge case:** If all active trays are in the germination period, the pump is skipped entirely for that event.

**Relationship to `BLACKOUT_DAYS`:** Both default to 2 and apply to the same window, but serve distinct purposes. `BLACKOUT_DAYS` controls lighting; `GERMINATION_WATER_DAYS` controls watering decisions. They can be set independently.

---

### Grow Cycle

#### `GROW_DAYS` — default `10`
Total grow cycle length in days. Once a tray reaches this day count, the button will seed it again on the next press.

```c
#define GROW_DAYS        10
```

Broccoli microgreens are typically ready at days 8–12 depending on light intensity and temperature.

#### `HARVEST_DAY` — default `8`
Grow day on which the harvest-ready red LED activates and the buzzer sounds once.

```c
#define HARVEST_DAY      8
```

Set this 2–3 days before GROW_DAYS as an advance notice. Harvest anytime between `HARVEST_DAY` and `GROW_DAYS`.

---

### Pump Parameters

#### `PUMP_RUN_SECONDS` — default `90` **[Calibrate]**
Seconds to run the pump for each scheduled watering event.

```c
#define PUMP_RUN_SECONDS     90
```

**This must be calibrated to your actual pump.** Target: 75 mL per event (25 mL × 3 trays). At 50 mL/min: 90 s. At 100 mL/min: 45 s. See Step 11 in [installation-guide.md](installation-guide.md) for measurement procedure.

Setting it too high will over-water (mould risk). Too low will under-water (wilting). The moisture feedback provides a safety net but cannot compensate for grossly wrong calibration.

#### `PUMP_TOPUP_SECONDS` — default `30`
Seconds to run the pump for a top-up pass after the main event.

```c
#define PUMP_TOPUP_SECONDS   30
```

A top-up runs after the main event if, after `MOISTURE_SETTLE_SECONDS` of settling time, any active tray still reads below `MOISTURE_TOPUP_THRESHOLD`. This handles cases where one tray has unusually high evaporation (e.g. older seedlings consuming more water). The top-up is a single additional run, not repeated.

#### `MOISTURE_SETTLE_SECONDS` — default `30`
Seconds to wait between stopping the pump and re-reading moisture sensors.

```c
#define MOISTURE_SETTLE_SECONDS  30
```

Coir absorbs water gradually. Reading too soon after pumping will show falsely low moisture levels. 30 seconds is a practical minimum; increase to 60 s for very dense coir or long tube runs.

---

### Moisture Thresholds

#### `MOISTURE_SKIP_THRESHOLD` — default `70`
If ALL active trays read at or above this moisture percentage, the scheduled watering event is skipped entirely.

```c
#define MOISTURE_SKIP_THRESHOLD   70    // % (0–100)
```

Purpose: prevents over-watering on days where the coir is still holding enough moisture from the previous event. Common causes of consistently high moisture: cool ambient temperatures, low evaporation on young trays (days 0–3), or pump calibration over-delivering.

Raise this value if the pump runs too rarely. Lower it if mould appears (over-watering).

#### `MOISTURE_TOPUP_THRESHOLD` — default `25`
After the main pump run + settling time, if any active tray reads at or below this value, a top-up pass runs.

```c
#define MOISTURE_TOPUP_THRESHOLD  25    // % (0–100)
```

Purpose: catches the case where one tray is significantly drier than the others after a standard pump run. Typical cause: tray at peak growth (day 6–9) has high water demand and the standard 75 mL split across three trays is insufficient for that tray alone.

Raise this value if trays dry out between events. Lower it (or set to 0 to disable top-up) if top-up runs are triggering unnecessarily.

---

### Moisture Sensor Calibration

#### `MOISTURE_DRY_RAW` — default `3200` **[Calibrate]**
Raw 12-bit ADC count (0–4095) when the sensor is held in dry air.

```c
#define MOISTURE_DRY_RAW   3200
```

This is the 0 % moisture reference. Typical range: 2900–3400. Values below 2800 or above 3600 suggest a wiring problem (check 3.3 V supply and GND to sensor).

#### `MOISTURE_WET_RAW` — default `1200` **[Calibrate]**
Raw 12-bit ADC count when the sensor is fully submerged in clean water.

```c
#define MOISTURE_WET_RAW   1200
```

This is the 100 % moisture reference. Typical range: 900–1500. The firmware maps all readings linearly between these two bounds.

**Calibration procedure:** See Step 10 in [installation-guide.md](installation-guide.md).

**Note on sensor-to-sensor variation:** All three sensors can have slightly different raw values. If one sensor consistently reads differently from the others in identical conditions, calibrate its thresholds by adjusting the raw constants. If the variation is large (>300 counts), replace the sensor.

---

### Sleep Interval

#### `SLEEP_SECONDS` — default `60`
Seconds between main-loop wakeups. The ESP32 is in light sleep between iterations.

```c
#define SLEEP_SECONDS    60
```

During light sleep the ESP32 draws ~0.8 mA instead of ~80 mA active. GPIO output states (relay on/off) are preserved. The schedule check runs once per wakeup, so there is up to `SLEEP_SECONDS` of latency on schedule transitions (e.g. lights may turn on up to 60 s after `PHOTO_ON_HOUR`).

Reducing to 30 s halves the transition latency at the cost of slightly higher average power draw. Increasing to 120 s would approximately halve the ESP32's average current with minimal practical effect.

Pressing the BOOT button wakes the CPU immediately from light sleep regardless of this setting.

---

### GPIO Pin Assignments

These define which ESP32 GPIO each function uses. **Do not change unless you have physically rewired your build.** Changes must match `wiring-schematic.md` exactly.

```c
// Relay outputs (LOW-level trigger: LOW = relay ON = load ON)
#define PIN_RELAY_LED_A   26    // LED strip Tray A
#define PIN_RELAY_LED_B   27    // LED strip Tray B
#define PIN_RELAY_LED_C   25    // LED strip Tray C
#define PIN_RELAY_PUMP    13    // Peristaltic pump

// Analog inputs (ADC1 only)
#define PIN_MOISTURE_A    34    // Moisture sensor Tray A
#define PIN_MOISTURE_B    35    // Moisture sensor Tray B
#define PIN_MOISTURE_C    32    // Moisture sensor Tray C

// Digital input
#define PIN_FLOAT_SWITCH  33    // Reservoir float switch

// Status outputs
#define PIN_LED_GREEN     18    // Heartbeat green LED
#define PIN_LED_YELLOW    19    // Water-low yellow LED
#define PIN_LED_RED_A      5    // Tray A harvest red LED
#define PIN_LED_RED_BC    17    // Tray B+C harvest red LED
#define PIN_BUZZER        16    // Active buzzer

// User button
#define PIN_BUTTON         0    // BOOT button

// I2C
#define PIN_SDA           21
#define PIN_SCL           22
```

**Why these pins:** See `wiring-schematic.md` Section 3.3 for full rationale. Key constraints: GPIO34/35 are ADC1 input-only pins (ideal for sensors); GPIO12 avoided (flash voltage strapping pin); ADC2 pins avoided (disabled during WiFi use).

---

### I2C Addresses

```c
#define RTC_I2C_ADDR    0x68   // DS3231 (hardware-fixed, cannot change)
#define OLED_I2C_ADDR   0x3C   // SSD1306 (try 0x3D if display not found)
```

Some SSD1306 modules have address `0x3D` instead of `0x3C` depending on a solder bridge on the module board. If the OLED is installed but not detected, change to `0x3D` and re-flash.

---

## Serial Commands

The firmware accepts commands via the Arduino Serial Monitor at **115200 baud**:

| Command | Example | Effect |
|---|---|---|
| `T<epoch>` | `T1739836800` | Set the RTC to the given Unix timestamp |
| `S` | `S` | Print full status dump (tray state, pump log, alarm flags) |

To get the current Unix timestamp: [https://www.unixtimestamp.com](https://www.unixtimestamp.com)

---

## Firmware Behaviour Summary

### On button press (BOOT / GPIO0)
The first available tray (in order A → B → C) with `seed_epoch == 0` or `day >= GROW_DAYS` is recorded as seeded at the current timestamp. Three green LED flashes confirm. If all three trays are active, five red flashes indicate "no tray available."

### Lights
Each tray's LED relay is controlled independently. Light turns ON when:
- Tray day > `BLACKOUT_DAYS` **AND**
- Current hour is in `[PHOTO_ON_HOUR, PHOTO_OFF_HOUR)`

Otherwise light is OFF. Empty trays (day = -1) always have lights off.

### Watering
Two events per day at `WATER_HOUR_1` and `WATER_HOUR_2`. For each event:
1. Read moisture for all active trays
2. If all active trays ≥ `MOISTURE_SKIP_THRESHOLD`: skip (no pump run)
3. Otherwise: run pump for `PUMP_RUN_SECONDS`
4. Wait `MOISTURE_SETTLE_SECONDS`
5. Re-read moisture; if any tray < `MOISTURE_TOPUP_THRESHOLD`: top-up run

Pump log (which events have fired today) is stored in EEPROM and resets at midnight.

### Alarms
- **Water low:** Float switch → GPIO33 LOW → yellow LED on, two buzzer beeps (once per transition, not every loop)
- **Harvest ready:** Tray day ≥ `HARVEST_DAY` → red LED on, one buzzer beep (once per tray, on first detection)
- **Heartbeat:** Green LED blinks slowly (1 s period) when system OK; fast (200 ms) when any alarm is active

### Power
The ESP32 enters light sleep for `SLEEP_SECONDS` between loop iterations. During light sleep:
- GPIO output states are preserved (relays stay in their current position)
- CPU and WiFi clocks stop (~0.8 mA from 3.3 V rail)
- A button press on GPIO0 wakes the CPU immediately

Average ESP32 power at 60 s sleep: ~2–3 mA vs ~80 mA continuously active.

---

## Optional / Future Enhancements

- **WiFi MQTT telemetry:** The ESP32 has built-in WiFi. Firmware could publish grow-day, moisture, and alarm state to an MQTT broker for remote monitoring. Disabled by default to conserve power.
- **Temperature/humidity sensor:** A DHT22 or SHT31 could log growing chamber conditions. Pin E12 (DS18B20) is on the BOM as an optional addition.
- **Data logging:** EEPROM or an SD card could store watering event history and moisture trends.
- **Web configuration:** A captive-portal WiFi interface could allow schedule changes without reflashing.

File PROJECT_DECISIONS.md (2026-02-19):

# Project Decisions Log

**Project:** Microgreen Growing Device
**Last Updated:** 2026-02-18 (Published to GitHub — DECISION-027/028; consistency fixes; README/CONTRIBUTING/LICENSE)
**Purpose:** This document is the single source of truth for the entire project. Any new Claude instance should read this file first and treat its contents as authoritative before taking any action.

---

## How to Use This Document

- **Before starting work:** Read this entire file.
- **After each session:** Update all relevant sections.
- **Conflicts:** If anything in the codebase or other docs contradicts this file, flag it and resolve before proceeding.

---

## Project Goal

Design and build a self-contained, automated device that produces broccoli microgreens for one person's daily health needs. Operates on 12V DC (solar/battery or vehicle). Low cost, 3D-printable, vehicle-compatible.

**Species locked:** Broccoli (*Brassica oleracea* var. *italica*)

---

## ⚠️ CONFLICT FLAG — DECISION-006 Amended by DECISION-007

Phase 01 DECISION-006 specified **compost/soil** as the growing medium for 73% higher mineral content. Phase 02 design revealed that **claude.md explicitly specifies coir** as a design input, and that the mandatory vehicle-compatibility requirement makes compost/soil impractical (heavy, messy, spills during motion). **DECISION-007 supersedes DECISION-006.** Coir is the mandatory growing medium. Mineral recovery is partially addressed by optional liquid supplement in watering water.

---

## Phase Status

| Phase | Status | Last Updated | Notes |
|---|---|---|---|
| 01 Research | **Complete** | 2026-02-17 | All 5 research docs written |
| 02 Design | **Complete** | 2026-02-18 | All 8 design docs written; consistency fixes applied (DECISION-027) |
| 03 Build | **Complete** | 2026-02-18 | All deliverables done; see Phase 03 section for full list |
| 04 Software | **Complete** | 2026-02-18 | Firmware + docs written; see Phase 04 section |
| 05 Publication | **Complete** | 2026-02-18 | Published to GitHub — see DECISION-027/028 |

---

## Decisions Made

### [DECISION-001] Target Species: Broccoli Microgreens Only
- **Date:** 2026-02-17
- **Decision:** Device optimized for broccoli microgreens only.
- **Rationale:** Highest sulforaphane (GRN) concentration of any readily growable microgreen; comparable to broccoli sprouts; 10–100× more SFN than mature broccoli.
- **Alternatives:** Radish (harsh flavor), sunflower (no SFN), pea shoots (no SFN).
- **Status:** Active

### [DECISION-002] Daily Production Target: 30 g/day (primary), 60 g/day (max)
- **Date:** 2026-02-17
- **Decision:** 30 g/day primary target; 60 g/day design capacity.
- **Rationale:** 30g delivers ~192–216 µmol SFN/day — upper range of well-studied clinical doses. 16g is the validated minimum; 30g provides meaningful safety buffer.
- **Impact:** Drives tray count (3), enclosure size, reservoir capacity.
- **Status:** Active

### [DECISION-003] Primary Consumption: Fresh Morning Smoothie
- **Date:** 2026-02-17
- **Decision:** Device outputs fresh-cut greens for daily raw smoothie consumption.
- **Rationale:** Blending maximizes myrosinase activation (= maximum sulforaphane), masks broccoli flavor, integrates into daily routine.
- **Impact:** No on-device processing required.
- **Status:** Active

### [DECISION-004] Preservation: Fresh Refrigeration Primary; Raw Freezing Secondary
- **Date:** 2026-02-17
- **Decision:** No on-device preservation hardware. Fresh greens refrigerated ≤7 days. Surplus frozen raw (unblanched) at −20°C; consumed by blending from frozen.
- **Rationale:** Raw home freezing increases sulforaphane yield up to 3.1× (FINDING-011). Free. Freeze-dryers are $2,000–$5,000 — out of scope.
- **Impact:** No preservation subsystem in device. Preservation System doc is a workflow document, not a hardware spec.
- **Status:** Active

### [DECISION-005] Tray Format: 25×25 cm (625 cm²), 3-Tray Staggered Rotation
- **Date:** 2026-02-17
- **Decision:** 3 trays of 25×25 cm in a vertical staggered rotation, harvesting one tray every ~3 days.
- **Rationale:** Square trays fit a compact 30×30cm column. At 90–130g yield per tray, 3-tray harvest every 3 days = 30–43 g/day.
- **Impact:** Enclosure footprint 30×30cm, height 85cm.
- **Status:** Active

### [DECISION-006] ~~Growing Medium: Compost/Soil~~ — SUPERSEDED BY DECISION-007
- **Date:** 2026-02-17
- **Status:** Superseded by DECISION-007

### [DECISION-007] Growing Medium: Coir (Amends DECISION-006)
- **Date:** 2026-02-17
- **Decision:** Use compressed coconut coir as growing medium. Optional dilute liquid mineral supplement (CalMag, 0.5 mL/L) added to watering water from day 3 onward.
- **Rationale:** claude.md explicitly lists "coir" as a required input. Vehicle-compatibility requirement makes compost/soil impractical: heavy, messy, prone to spillage in motion. Coir is lightweight, fibrous (stable in motion), clean, and widely available as compressed pucks.
- **Mineral trade-off:** Coir has lower inherent mineral content than compost (~73% lower based on USDA data). Liquid supplement partially compensates. The primary nutritional value of these microgreens is sulforaphane (not minerals), so the trade-off is acceptable.
- **Alternatives:** Compost (ruled out — vehicle incompatible), hydroponic mats (lower yield, no mineral benefit, adequate for coir-free vehicle use).
- **Impact:** Tray design does not need drainage for soil; coir is self-contained. Watering is simpler. Consumables change (coir pucks instead of potting mix).
- **Status:** Active

### [DECISION-008] Microcontroller: ESP32
- **Date:** 2026-02-17
- **Decision:** ESP32 (ESP32-WROOM-32 dev board) is the system controller.
- **Rationale:** $4–8 USD, Arduino IDE compatible, 34 GPIO pins, hardware I2C/SPI, 12-bit ADC, built-in WiFi (optional use), deep sleep mode (10µA) for battery preservation, 4MB flash.
- **Alternatives:** Arduino Nano (no WiFi, less RAM), RPi Zero (500mA power, complex boot), ATtiny85 (insufficient I/O).
- **Impact:** All firmware written for ESP32/Arduino framework. 3.3V logic; 5V input via on-board regulator from 12V buck converter.
- **Status:** Active

### [DECISION-009] Power System: 12V DC, Solar + LiFePO4 Battery
- **Date:** 2026-02-17
- **Decision:** 12V DC primary supply. Off-grid: 40W solar panel + 20Ah LiFePO4 battery + 10A MPPT controller. Vehicle: direct 12V connection via cigarette lighter/Anderson Powerpole. Home: 12V/2A mains adapter.
- **Rationale:** claude.md mandates 12V or 5V solar/battery. Average load 5.6W / 134 Wh/day. 40W panel at 4 peak sun hours × 0.85 efficiency = 136 Wh/day — breaks even. 20Ah LiFePO4 = 192 Wh usable = 34 hours autonomy on battery alone.
- **Alternatives:** 5V USB (insufficient for 9W LED load), mains-only (contradicts off-grid requirement), LiPo battery (fire risk in hot vehicle), lead-acid (too heavy).
- **Impact:** All 12V DC loads. On-board buck converter to 5V for ESP32. Inline 5A fuse. Reverse polarity protection.
- **Status:** Active

### [DECISION-010] Lighting: 3W Full-Spectrum LED per Tray, 14h Photoperiod
- **Date:** 2026-02-17
- **Decision:** Each tray level has a 3W 5000–6500K full-spectrum LED panel at 10cm above tray surface. Photoperiod: 14h on / 10h off. Software-controlled blackout for days 0–2 per tray (no physical cover needed).
- **Rationale:** 3W efficient LED → ~100 µmol/m²/s PPFD at 625 cm² tray — balanced for sulforaphane and vitamins (FINDING-009). Full spectrum simpler than red+blue bichromatic. 14h photoperiod balances yield and power budget (saves ~30% vs 16h with minimal yield impact). 9W total lighting keeps power budget within solar capacity.
- **Alternatives:** Red+blue bichromatic (more efficient but purple light, complex drivers), 5W per panel (adequate PPFD but increases solar panel requirement to ~80W), 16h photoperiod (higher yield, but 30% more energy = larger solar panel needed).
- **Impact:** LED relays: 3 channels on relay module. Each panel independently switched. Total lighting: 9W peak, 5.25W average.
- **Status:** Active

### [DECISION-011] Watering: Top-Drip Peristaltic Pump, Twice Daily
- **Date:** 2026-02-17
- **Decision:** 12V peristaltic pump draws from sealed 2L reservoir; delivers ~25 mL per tray per event via top-drip; 2 events/day (07:00 and 19:00). All water fully enclosed — sealed reservoir, sealed sub-trays, sealed waste chamber.
- **Rationale:** Peristaltic pump self-priming, works in any orientation (critical for vehicle), dry-run safe. Top-drip into coir leaves no standing open water — vehicle-stable. 2L reservoir at 150 mL/day use = 13+ day autonomy. Bottom-flood watering requires open water in sub-trays — unacceptable for vehicle.
- **Alternatives:** Bottom flood/drain (open water — not vehicle-safe), wicking (passive but hard to control), misting (humid environment risk, complex).
- **Impact:** 1 relay channel for pump. Manifold splits to 3 drip emitters. Capacitive water level sensor in reservoir. Waste chamber collects overflow.
- **Status:** Active

### [DECISION-012] Enclosure: PETG 3D-Printed Vertical Column, 300×300×850mm
- **Date:** 2026-02-17
- **Decision:** Modular vertical column in PETG: base unit (reservoir + electronics) + 3× tray level rings + top cap. All parts print on 200×200mm bed. Front-opening hinged doors per tray level. No support structures needed (designed for support-free FDM printing).
- **Rationale:** PETG is food-safe, moisture-resistant, and heat-stable to 80°C (safe in vehicles). Modular ring design allows scaling by adding rings. Low center of gravity (reservoir at base) provides vehicle stability. 300mm footprint fits within 35cm constraint.
- **Alternatives:** Laser-cut plywood (not 3D-printable, water-damaged), aluminum extrusion (expensive, heavy), injection-molded (requires tooling), PLA (heat-sensitive, degrades in moisture).
- **Impact:** ~2.4 kg PETG, ~65 print-hours. Reservoir interior requires waterproofing coat (XTC-3D or shellac). PETG only — no PLA for structural/water-contact parts.
- **Status:** Active

---

## Key Findings

### [FINDING-001] Sulforaphane Concentration in Broccoli Microgreens
- **Date:** 2026-02-17
- **Finding:** GRN: ~12.8–13.6 µmol/g fresh weight; SFN potential: ~6.4–7.2 µmol/g. 16g serving = 100 µmol SFN (clinically validated).
- **Source:** PMC10606698
- **Confidence:** High

### [FINDING-002] 10–100× More Sulforaphane Than Mature Broccoli
- **Date:** 2026-02-17
- **Finding:** Conservative: 10–40×. 73% more minerals (compost-grown). 93–95% less water; 158–236× less land.
- **Source:** PMC10606698, PMC5362588
- **Confidence:** High

### [FINDING-003] Myrosinase Destroyed Above 60–70°C
- **Date:** 2026-02-17
- **Finding:** Raw consumption required for sulforaphane. Chop and wait 40 min before heat. Mustard seed powder provides exogenous myrosinase.
- **Source:** PMC7174218, CPBL blog
- **Confidence:** High

### [FINDING-004] Optimal Dose: 50–150 µmol SFN/day
- **Date:** 2026-02-17
- **Finding:** Clinical range 50–150 µmol/day. 30g target = ~200 µmol/day — upper end of well-studied range.
- **Source:** PMC6804255, PMC10606698
- **Confidence:** High

### [FINDING-005] Larger Doses Not Simply Better
- **Date:** 2026-02-17
- **Finding:** Complex hormetic dose-response. GI discomfort above 150–400 µmol/day. Consistent daily modest dose preferred over episodic high dose.
- **Source:** PMC6804255, PMC4273949
- **Confidence:** Medium

### [FINDING-006] Capsule Delivery Feasible But Not Primary
- **Date:** 2026-02-17
- **Finding:** 30g fresh → 1.5g freeze-dried powder → 2–3 size 0 capsules. Requires freeze-dryer ($2k–5k). Commercial products exist.
- **Source:** Commercial research
- **Confidence:** High

### [FINDING-007] Tray Yield: 90–130g per 25×25cm Tray in 10 Days
- **Date:** 2026-02-17
- **Finding:** Based on scaled commercial data. Conservative 90g; typical 110g; optimistic 130g. 3-tray rotation: 30–43 g/day.
- **Source:** PMC5362588, Bootstrap Farmer, Johnny's Seeds Yield Trial
- **Confidence:** Medium (validate with prototype)

### [FINDING-008] Compost vs. Coir: 73% More Minerals in Compost
- **Date:** 2026-02-17
- **Finding:** USDA study. Coir is vehicle-compatible but mineral-poor. Liquid supplement (CalMag) partially compensates.
- **Source:** PMC5362588
- **Confidence:** High

### [FINDING-009] Light Intensity Affects Nutritional Profile
- **Date:** 2026-02-17
- **Finding:** 100–150 µmol/m²/s → more carotenoids/anthocyanins. 50–75 → more vitamin C/phenolics. 100 µmol/m²/s balances both.
- **Source:** Literature review
- **Confidence:** Medium

### [FINDING-010] YouTube Channel @continuousharvest5822
- **Date:** 2026-02-17
- **Finding:** Cannot be fetched programmatically. Review manually. URL: https://www.youtube.com/@continuousharvest5822
- **Confidence:** N/A

### [FINDING-011] Raw Home Freezing Increases Sulforaphane Up to 3.1×
- **Date:** 2026-02-17
- **Finding:** −20°C home freezing of raw unblanched microgreens increases myrosinase activity +17–117% and SFN yield up to 3.1×. GRN fully preserved. Blend from frozen immediately — do not thaw. Commercial frozen broccoli is blanched (kills myrosinase) — completely different.
- **Source:** RSC Advances c5ra03403e; Jed Fahey / FoundMyFitness; PubMed 23915112
- **Confidence:** High

### [FINDING-012] Vehicle Requirement Changes Design Fundamentally
- **Date:** 2026-02-17
- **Finding:** claude.md's "must work in moving vehicles" requirement drives: (1) coir instead of compost — lightweight, fibrous, non-spill; (2) sealed reservoir and sub-trays — no open water; (3) peristaltic pump — works in any orientation; (4) wide low-CG enclosure; (5) positive-lock tray retention; (6) 12V DC supply compatible with vehicle electrical system.
- **Source:** claude.md design goals; Phase 02 design work
- **Confidence:** High (design constraint)

### [FINDING-013] 5.6W Average Power — 40W Solar Achieves Energy Balance
- **Date:** 2026-02-17
- **Finding:** Full system average load: 5.6W = 134 Wh/day. 40W panel at 4 peak sun hours × 0.85 efficiency = 136 Wh/day. Effectively break-even. 50W panel provides comfortable surplus. 20Ah LiFePO4 = 34h autonomy on battery alone.
- **Source:** Phase 02 power calculations
- **Confidence:** High (calculated from specifications)

---

## Open Questions

| ID | Question | Blocks | Priority | Notes |
|----|---|---|---|---|
| Q-001 | Actual yield of 25×25cm tray with coir under 100 µmol/m²/s | Confirm DECISION-005 | High | Validate by prototype; current estimate 90–130g |
| Q-003 | Automated harvest notification vs. simple timer LED | Phase 04 software | Low | Recommend timer-based LED for simplicity |
| Q-004 | Fresh shelf life with dry refrigerated storage | DECISION-004 | Medium | 5–7 days consensus |
| Q-005 | @continuousharvest5822 YouTube channel content | Growing system detail | Medium | Manual review required |
| Q-008 | What PETG waterproofing method is most practical? XTC-3D vs. shellac vs. dedicated sealant? | Enclosure build | Medium | Test on small print before full build |
| Q-009 | Does the 3W LED panel (3× efficiency) achieve 100 µmol/m²/s at 10cm over 625 cm²? | Lighting spec | Medium | Measure with PAR meter on prototype; 5W panel is fallback |
| Q-010 | What is the CalMag supplement dose effect on broccoli microgreen mineral content and flavor? | Growing system optimization | Low | Optional; primary nutrition from SFN, not minerals |

---

## Resolved Questions

| ID | Question | Resolution |
|----|---|---|
| Q-002 | Blackout method for germination | Software-controlled per-tray LED disable (days 0–2); no physical cover needed |
| Q-006 | Optimal seeding density | 12–15g per 25×25cm tray (0.19–0.24 g/cm²); pre-soak seed 4–8 hours |
| Q-007 | Water recirculation vs. drain-to-waste | Drain-to-waste into sealed waste chamber; recirculation adds complexity without benefit at these volumes |

---

## Phase 01: Research — Complete

All 5 documents written. Key outputs:
- Species: broccoli
- Daily target: 30g/day fresh
- Primary consumption: morning smoothie raw
- Preservation: fresh (primary) + raw frozen (secondary, increases SFN 3.1×)

---

## Phase 02: Design — Complete
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

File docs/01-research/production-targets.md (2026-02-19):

# Production Targets

**Phase:** 01 Research
**Status:** Complete
**Last Updated:** 2026-02-17

---

## Summary

The device should produce a minimum of **30 g/day fresh broccoli microgreens**, with a design target of **60 g/day** for flexibility and to accommodate therapeutic doses. At 30 g/day and a 10-day grow cycle, this requires a **staggered system of 3 trays** (one seeded every ~3 days), each approximately 25×25 cm (10"×10") or equivalent area. At 60 g/day, 6 trays or larger tray area is required. The system is designed around a **10-day grow cycle with daily harvest capability**.

---

## Inputs from Prior Research
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

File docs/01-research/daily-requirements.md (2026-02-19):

# Daily Nutritional Requirements and Recommended Dose

**Phase:** 01 Research
**Status:** Complete
**Last Updated:** 2026-02-17

---

## Summary

The target daily intake of broccoli microgreens is **30–60 g fresh weight per day** for general health and preventive benefits, with a therapeutic range of **113–142 g/day** for specific disease management. The primary dosing metric is sulforaphane (SFN): clinical research supports 50–150 µmol/day as a safe, effective range for healthy adults. At
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

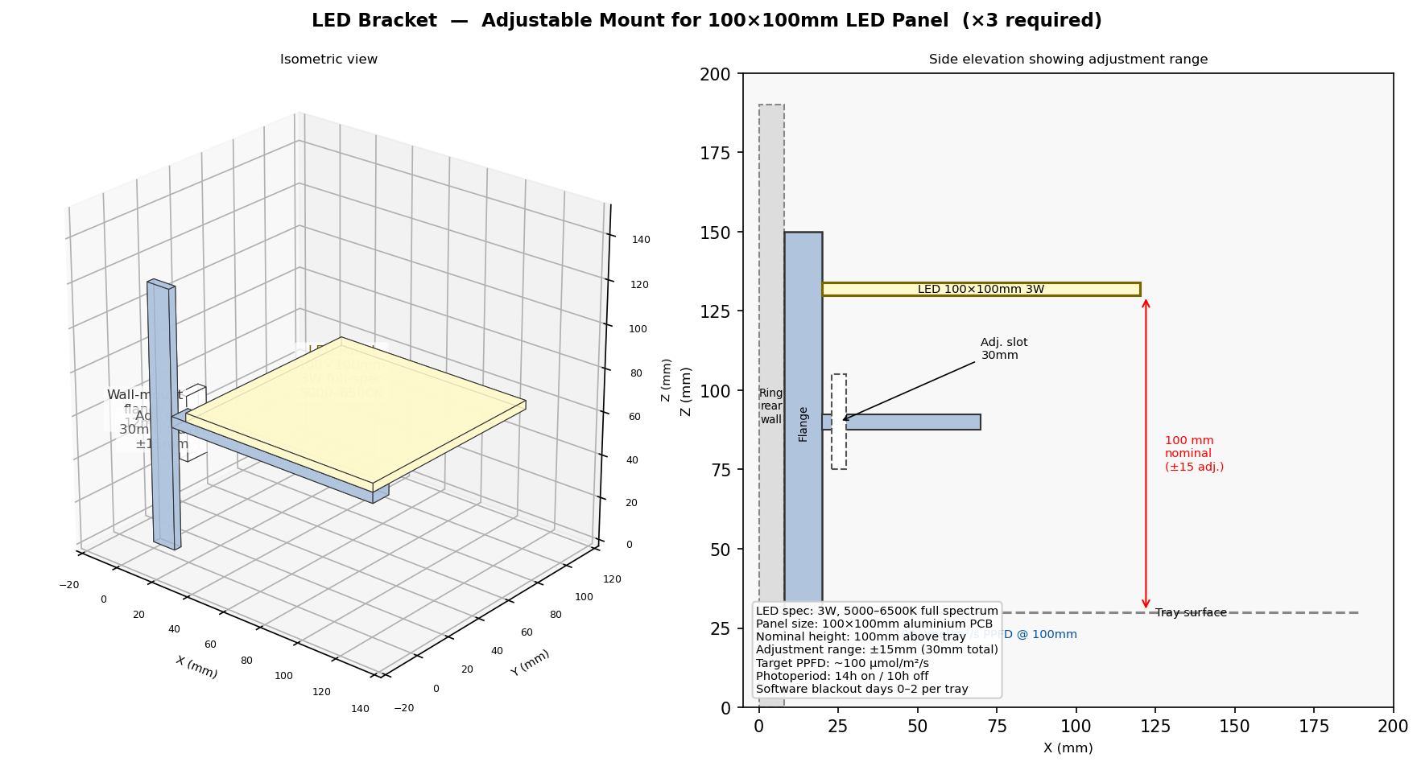
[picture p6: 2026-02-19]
hardware/3d-models/renders/06_led_bracket.png

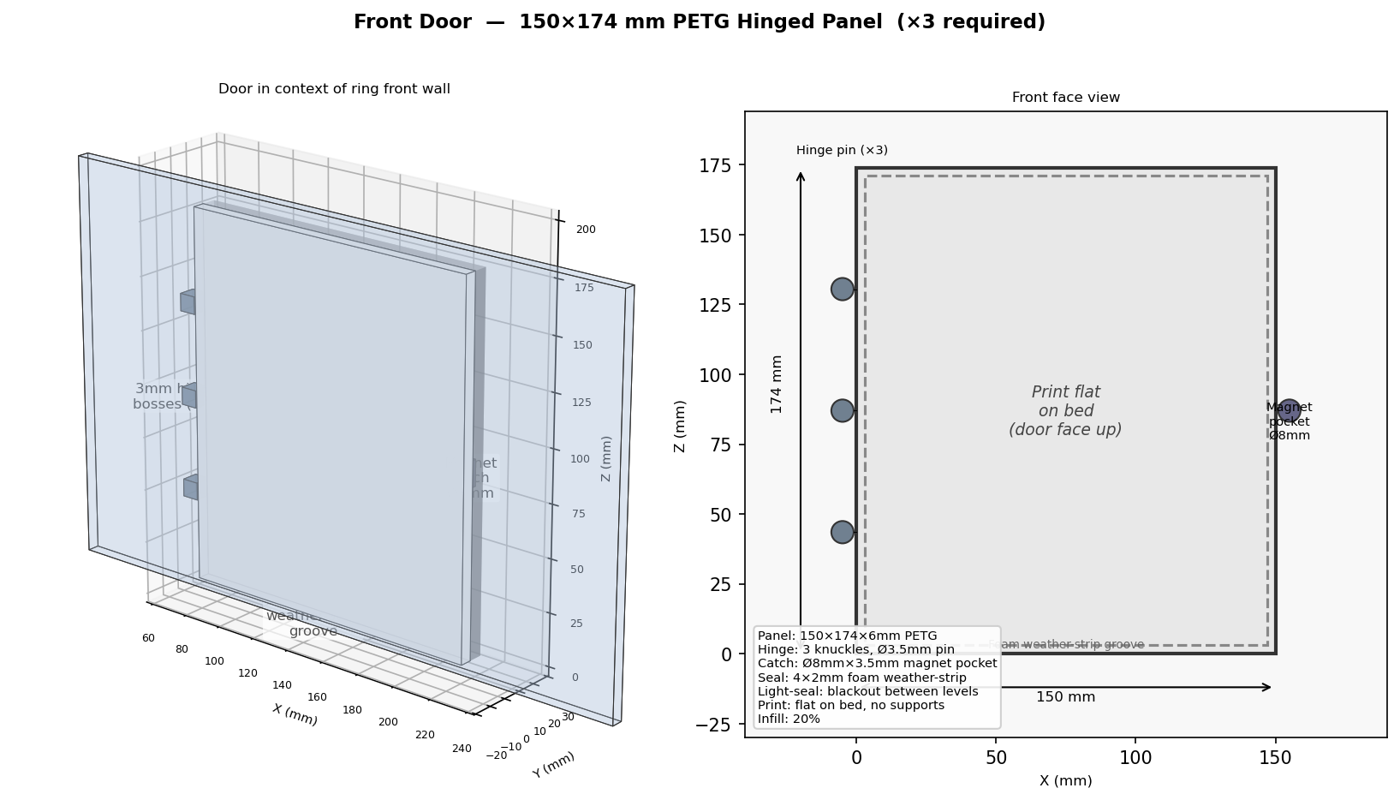
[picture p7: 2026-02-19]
hardware/3d-models/renders/07_tray_door.png

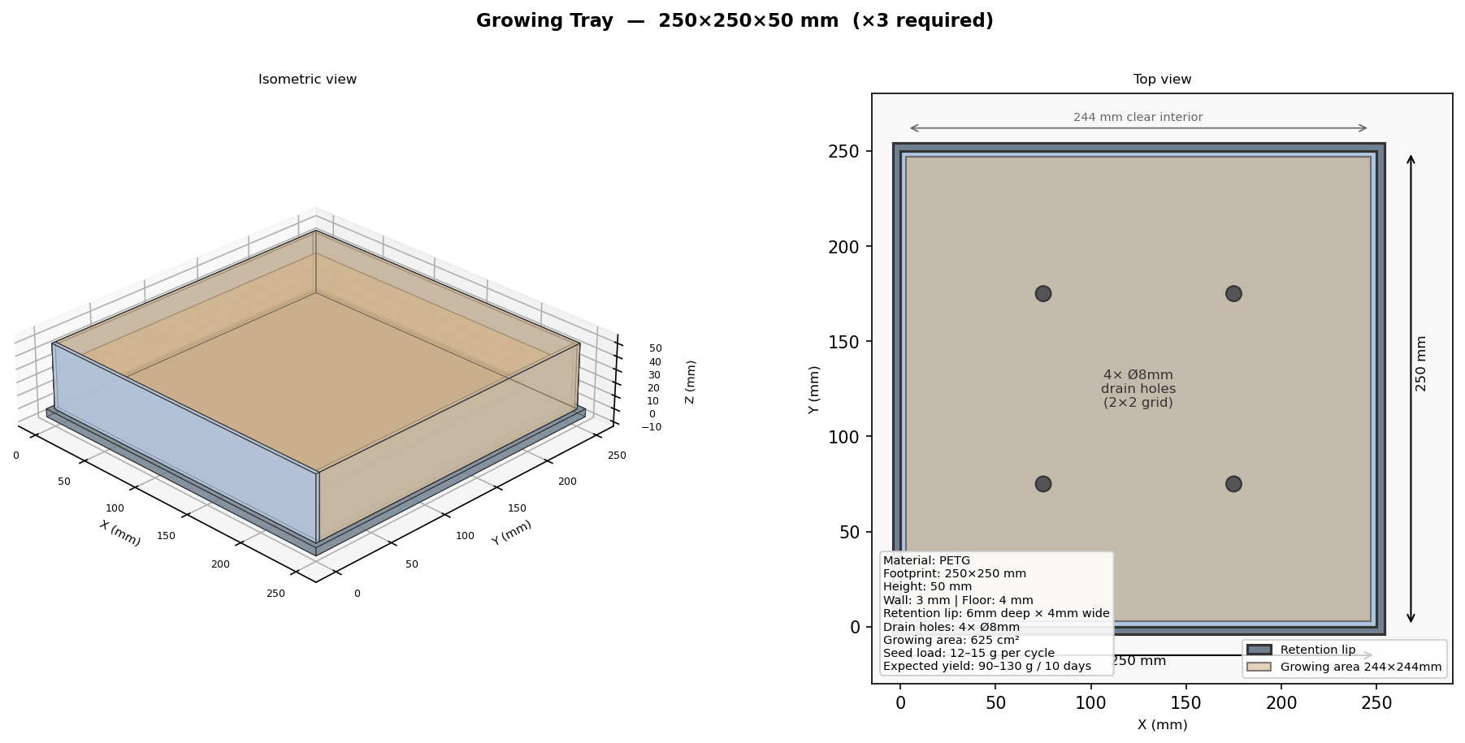
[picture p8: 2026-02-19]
hardware/3d-models/renders/04_growing_tray.png

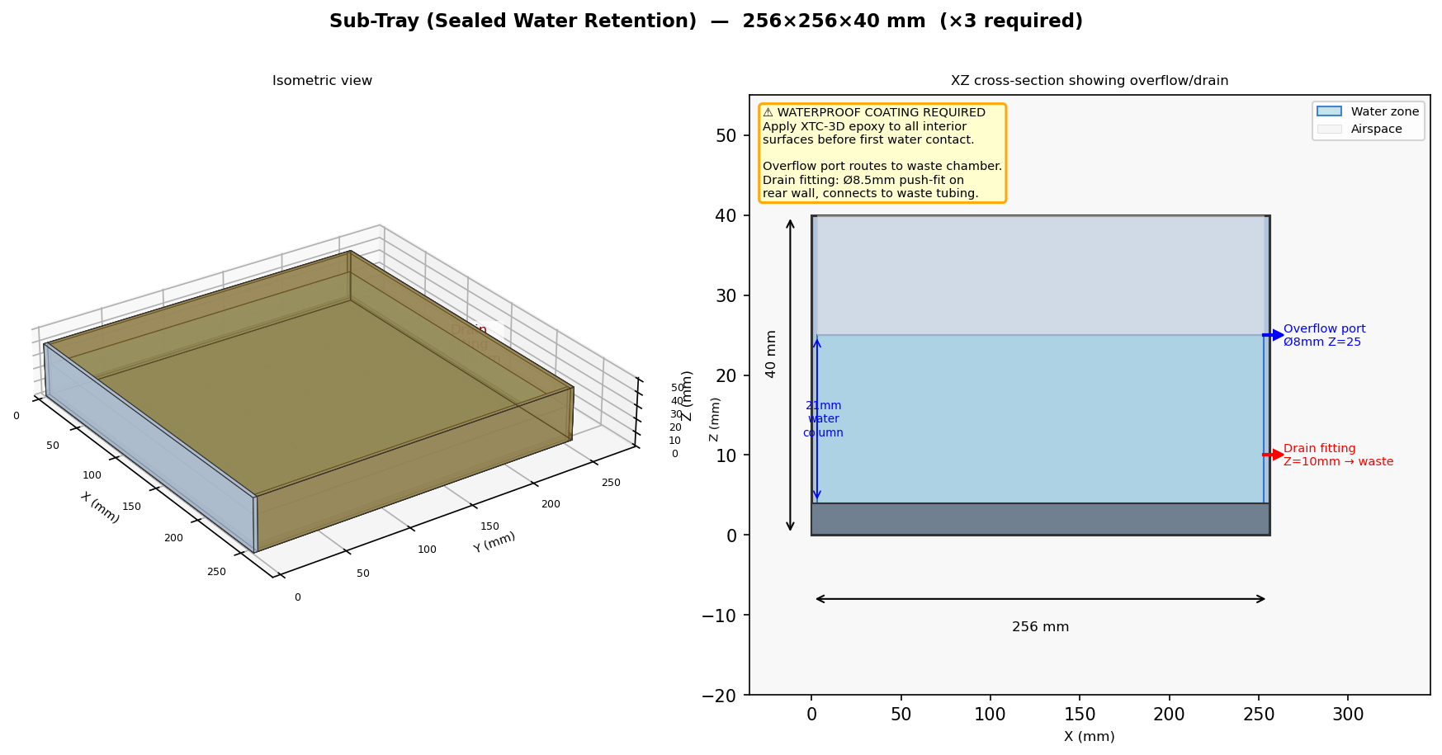
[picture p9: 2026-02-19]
hardware/3d-models/renders/05_sub_tray.png

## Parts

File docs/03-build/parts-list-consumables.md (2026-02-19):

# Consumables Parts List

**Phase:** 03 Build
**Status:** Complete
**Last Updated:** 2026-02-17

Consumables are items purchased repeatedly. All quantities are per month at the **30 g/day primary production target** (3-tray rotation, ~6 tray cycles/month).

---

## Seeds

| Item | Specification | Supplier | Est. Price | Monthly Use | Monthly Cost | Notes |
|---|---|---|---|---|---|---|
| Broccoli microgreen seed | Untreated, non-GMO, food-grade; De Cicco, Calabrese, or Waltham 29 variety | True Leaf Market, Johnny's Seeds, AliExpress (bulk), local health food store | $15–30/kg | ~90 g/month (6 trays × 15g) | **$1.35–2.70/month** | Buy 500g–1kg at a time; store sealed, dark, dry |

**Annual seed cost: ~$16–33**

> Tip: "Broccoli sprouting seed" is identical to microgreen seed and often cheaper. Do not use treated seed (fungicide coatings common in garden seed packets — look for "untreated" or "organic").

---

## Growing Medium

| Item | Specification | Supplier | Est. Price | Monthly Use | Monthly Cost | Notes |
|---|---|---|---|---|---|---|
| Compressed coir puck | 50g compressed, expands to ~8× volume in water; 100% coir, no peat, no added nutrients | Amazon, AliExpress, garden centres | $5–10 per 10-pack | 6 pucks/month (1 per tray cycle) | **$3–6/month** | ~50g dry coir fills one 25×25×5cm tray to ~2cm depth. Rinse before use. |

**Annual coir cost: ~$36–72**

> Alternative: Buy a 650g coir brick ($5–8) and break off ~50g per tray. A single 650g brick provides ~13 tray fills.

---

## Water Additives (Optional)

| Item | Specification | Supplier | Est. Price | Monthly Use | Monthly Cost | Notes |
|---|---|---|---|---|---|---|
| Liquid CalMag supplement | Calcium + Magnesium liquid, e.g., General Hydroponics CALiMAGic, or Botanicare Cal-Mag Plus | Hydroponic supply stores, Amazon | $10–15 per 240mL bottle | ~30 mL/month (0.5 mL/L × 60L water used) | **$1.25–1.88/month** | Add from day 3 onward. At 0.5 mL/L this is very dilute — partially compensates for coir mineral deficit. Omit if mineral content not critical. |

**Annual CalMag cost: ~$15–23 (optional)**

---

## Harvest and Storage Supplies

| Item | Specification | Supplier | Est. Price | Monthly Use | Monthly Cost | Notes |
|---|---|---|---|---|---|---|
| Small zip-lock bags | 10cm × 8cm (4"×3"), food-grade, resealable | Amazon, dollar store | $3–5 per 100 | ~12–18 bags/month (frozen 30g portions) | **$0.50–0.90/month** | For frozen 30g portions. Label with permanent marker. |
| Paper towel (for fridge storage) | Standard household paper towel | Any | — | ~1 sheet/week | **~$0.50/month** | Line refrigerator container to absorb moisture; extends fresh shelf life |
| Permanent marker | Fine-tip, any colour | Any | $1 | 1 per year | **$0.08/month** | Date frozen bags |

**Annual harvest/storage cost: ~$13–17**

---

## Total Monthly and Annual Consumables Cost

| Item | Monthly Cost | Annual Cost |
|---|---|---|
| Broccoli seed | $1.35–2.70 | $16–33 |
| Coir pucks | $3.00–6.00 | $36–72 |
| CalMag supplement (optional) | $1.25–1.88 | $15–23 |
| Zip-lock bags | $0.50–0.90 | $6–11 |
| Paper towel | ~$0.50 | ~$6 |
| Permanent marker | ~$0.08 | ~$1 |
| **Total (with CalMag)** | **$6.68–12.06** | **$80–146** |
| **Total (without CalMag)** | **$5.43–10.18** | **$65–122** |

---

## Sourcing Notes

### Seeds
- **True Leaf Market** (trueLeafMarket.com): Best quality US source; sells by weight; broccoli microgreen seed $7–15/lb
- **Johnny's Selected Seeds**: High-quality commercial seed; broccoli sprouting/microgreen varieties
- **AliExpress** (bulk): Very low cost ($5–10/kg) but variable quality and longer shipping; useful for prototype
- **Mountain Rose Herbs**: Organic options

### Coir
- Any garden centre carries compressed coir pucks (marketed as "seed starter pellets" or "coir pots")
- Jiffy-7 peat pellets are NOT coir — check label; look for 100% coconut coir
- Hydroponic supply stores carry coir bricks at the best price per gram

### CalMag
- Available at any hydroponics shop
- General Hydroponics CALiMAGic: widely available; proven formulation
- Can omit entirely — device produces nutritious microgreens on coir alone; sulforaphane is unaffected by mineral supplement

---

## Scale-Up Reference (60 g/day / 4-tray mode)

| Item | Monthly Use | Monthly Cost |
|---|---|---|
| Seeds | ~180 g | $2.70–5.40 |
| Coir pucks | ~12 | $6–12 |
| CalMag (optional) | ~60 mL | $2.50–3.75 |
| Zip-lock bags | ~25–30 | $1.00–1.50 |
| **Total** | | **$12–23/month** |

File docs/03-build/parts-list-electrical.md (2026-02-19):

# Electrical Parts List

**Phase:** 03 Build
**Status:** Complete
**Last Updated:** 2026-02-17

All costs are approximate retail prices. AliExpress pricing typically 30–50% lower with 2–4 week delivery. Amazon pricing is 20–50% higher with faster delivery. Quantities for a single 3-tray unit.

---

## Control

| # | Component | Specification | Qty | Supplier | Search Term / Part | Unit Cost | Total | Notes |
|---|---|---|-----|---|---|---|---|---|
| E01 | Microcontroller | ESP32-WROOM-32 dev board, 38-pin, USB-UART | 1 | AliExpress / Amazon | "ESP32 38pin development board" | $5–8 | $6 | Arduino IDE compatible; see system-architecture.md |
| E02 | RTC module | DS3231, I2C, 3.3V/5V compatible, coin cell holder | 1 | AliExpress / Amazon | "DS3231 AT24C32 I2C RTC module" | $1–4 | $2 | Maintains time through power loss; CR2032 battery included |
| E03 | OLED display (optional) | 0.96" 128×64, I2C, SSD1306, 3.3V/5V | 1 | AliExpress / Amazon | "0.96 inch I2C OLED SSD1306" | $2–5 | $3 | Status display; omit if reducing cost |

**Control subtotal: ~$11**

---

## Power

| # | Component | Specification | Qty | Supplier | Search Term / Part | Unit Cost | Total | Notes |
|---|---|---|-----|---|---|---|---|---|
| E04 | Buck converter | MP1584EN, 4–28V input, 3A, adjustable output; set to 5V | 1 | AliExpress / Amazon | "MP1584 DC-DC step down buck module" | $1–2 | $1.50 | 12V → 5V for ESP32 |
| E05 | Fuse holder + fuse | Inline blade fuse holder + 5A automotive blade fuse | 1 | AliExpress / Amazon | "inline blade fuse holder 5A" | $1–2 | $1.50 | Protects 12V wiring |
| E06 | Reverse polarity protection | AO3401 P-channel MOSFET SOT-23; or 1N5400 diode (simpler, ~0.6V drop) | 1 | AliExpress / Digi-Key | "AO3401 P-ch MOSFET" | $0.50 | $0.50 | Prevents damage if 12V polarity reversed |
| E07 | Power input jack | 5.5/2.1mm DC barrel jack, panel-mount, positive-centre | 1 | AliExpress / Amazon | "5.5mm 2.1mm DC power jack panel mount" | $0.50–1 | $0.75 | Input connector for 12V supply |

**Power subtotal: ~$4.25**

---

## Lighting

| # | Component | Specification | Qty | Supplier | Search Term / Part | Unit Cost | Total | Notes |
|---|---|---|-----|---|---|---|---|---|
| E08 | LED grow panel | 12V, 3–5W, 100×100mm, full-spectrum 5000–6500K, aluminium PCB | 3 | AliExpress | "12V 5W LED grow light panel 100×100" | $5–12 | $21 | One per tray level; 3W target; 5W acceptable |
| — | **OR (DIY strip option)** | 12V 2835 LED strip, 60 LED/m, 4.8W/m, 6000K, IP30 (no waterproofing) | 2m | AliExpress | "12V 2835 LED strip 60LED 6000K" | $3–5/m | $8 | Cut 4×50cm strips per tray, mount on 3D-printed sled |

**Lighting subtotal: ~$21 (panel option) or ~$8 (DIY strip)**

---

## Actuators

| # | Component | Specification | Qty | Supplier | Search Term / Part | Unit Cost | Total | Notes |
|---|---|---|-----|---|---|---|---|---|
| E09 | Relay module | 4-channel, 5V coil, optocoupler isolated, 10A contacts, active-LOW input | 1 | AliExpress / Amazon | "4 channel 5V relay module optocoupler" | $3–6 | $4 | Controls 3× LED panels + 1× pump |
| E10 | Peristaltic pump | 12V DC, 40–100 mL/min, 4–6mm silicone tubing, food-grade | 1 | AliExpress / Amazon | "12V DC peristaltic pump dosing pump" | $8–18 | $12 | See watering-system.md |

**Actuator subtotal: ~$16**

---

## Sensors

| # | Component | Specification | Qty | Supplier | Search Term / Part | Unit Cost | Total | Notes |
|---|---|---|-----|---|---|---|---|---|
| E11 | Water level sensor | Capacitive non-contact, 5V or 3.3V output, XKC-Y25-V or equivalent | 1 | AliExpress / Amazon | "XKC-Y25-V capacitive water level sensor non-contact" | $3–8 | $5 | Mounts on exterior of PETG reservoir; no water contact |
| E12 | Temperature sensor (optional) | DS18B20 waterproof probe, 1-Wire, 3–5V, −55 to +125°C | 1 | AliExpress / Amazon | "DS18B20 waterproof temperature sensor" | $1–3 | $2 | Growing chamber temp monitoring; omit if reducing cost |

**Sensor subtotal: ~$7**

---

## Indicators

| # | Component | Specification | Qty | Supplier | Search Term / Part | Unit Cost | Total | Notes |
|---|---|---|-----|---|---|---|---|---|
| E13 | LED — power (green) | 3mm green LED, 2.1V forward voltage | 1 | AliExpress / electronics shop | "3mm green LED" | $0.10 | $0.10 | Power-on indicator |
| E14 | LED — water low (yellow) | 3mm yellow LED, 2.0V forward voltage | 1 | AliExpress / electronics shop | "3mm yellow LED" | $0.10 | $0.10 | Reservoir low alert |
| E15 | LED — harvest ready A (red) | 3mm red LED, 1.8V forward voltage | 1 | AliExpress / electronics shop | "3mm red LED" | $0.10 | $0.10 | Tray A harvest-ready |
| E16 | LED — harvest ready B+C (red) | 3mm red LED | 2 | AliExpress / electronics shop | "3mm red LED" | $0.10 | $0.20 | Tray B and C harvest-ready |
| E17 | Current-limiting resistors | 330Ω, 1/4W, ±5% | 10 | Any | "330 ohm resistor 1/4W" | $0.01 | $0.10 | For all status LEDs from 3.3V GPIO |
| E18 | Buzzer (optional) | 5V active buzzer, 85 dB, 12mm | 1 | AliExpress / Amazon | "5V active buzzer 12mm" | $0.50 | $0.50 | Low-water audible alert; omit if OLED display used |

**Indicator subtotal: ~$1.10**

---

## Wiring and Connectors

| # | Component | Specification | Qty | Supplier | Search Term / Part | Unit Cost | Total | Notes |
|---|---|---|-----|---|---|---|---|---|
| E19 | Hookup wire — heavy | 20 AWG, silicone-insulated (flexible), red and black, 3m each | 6m | AliExpress / Amazon | "20AWG silicone wire red black" | $0.80/m | $4.80 | 12V power runs (LED panels, pump, bus) |
| E20 | Hookup wire — light | 24 AWG, silicone or PVC, multi-colour, 2m | 6m | AliExpress / Amazon | "24AWG hookup wire" | $0.40/m | $2.40 | Signal wires (GPIO to relays, sensors, LEDs) |
| E21 | JST-XH 2-pin connectors | Male + female pairs, 2.54mm pitch (or 2mm pitch) | 10 pairs | AliExpress | "JST XH 2 pin connector pair" | $0.15/pair | $1.50 | Quick-disconnect for LED panels, pump |
| E22 | JST-XH 4-pin connectors | Male + female pairs | 5 pairs | AliExpress | "JST XH 4 pin connector pair" | $0.20/pair | $1.00 | Sensor connections |
| E23 | Prototype/stripboard | 5×7cm double-sided stripboard | 1 | AliExpress / Amazon | "5x7cm stripboard PCB prototype" | $0.50–1 | $0.75 | For soldering buck converter, fuse, protection circuit |
| E24 | Pin headers (male) | 2.54mm, 40-pin strips | 2 | AliExpress | "2.54mm male pin header strip 40pin" | $0.30 | $0.60 | For connecting ESP32 to breadboard or stripboard |
| E25 | Heat shrink tubing | Assorted 2mm/4mm/6mm, 1m each | 3m | AliExpress / Amazon | "heat shrink tubing assorted" | $1.50 | $1.50 | Insulating solder joints |
| E26 | Ferrule terminals | 0.75mm² (20AWG), 100 pack | 1 | AliExpress | "ferrule terminals 20AWG 0.75mm" | $2–3 | $2.50 | For secure screw terminal connections |

**Wiring subtotal: ~$15.05**

---

## Cost Summary

| Category | Subtotal |
|---|---|
| Control (ESP32, RTC, OLED) | $11.00 |
| Power (buck converter, fuse, protection, jack) | $4.25 |
| Lighting (3× LED panels) | $21.00 |
| Actuators (relay module + pump) | $16.00 |
| Sensors (water level + temp) | $7.00 |
| Indicators (LEDs, buzzer) | $1.10 |
| Wiring and connectors | $15.05 |
| **Electronics total** | **~$75.40** |

> Note: LED DIY strip option reduces lighting cost to ~$8, bringing electronics total to ~$62. All prices assume AliExpress sourcing. Amazon sourcing adds ~30–50%.

---

## Solar / Off-Grid Option (separate from core BOM)

| # | Component | Specification | Qty | Search Term | Est. Cost |
|---|---|---|-----|---|---|
| S01 | Solar panel | 40W monocrystalline 12V, Voc ~21V | 1 | "40W 12V monocrystalline solar panel" | $30–45 |
| S02 | MPPT charge controller | 10A, 12V/24V auto, with USB port | 1 | "10A MPPT solar charge controller 12V" | $15–25 |
| S03 | LiFePO4 battery | 12V 20Ah, with built-in BMS | 1 | "12V 20Ah LiFePO4 battery" | $45–70 |
| S04 | Solar cable + MC4 connectors | 10AWG, 3m pair | 1 | "MC4 solar cable 10AWG" | $6–10 |
| S05 | Battery cable + Anderson PP45 | 10AWG, 1m pair | 1 | "Anderson Powerpole PP45 connector" | $4–8 |
| — | **Solar subtotal** | | | | **$100–158** |

**Grand total (device + solar): ~$175–233**

---

## Wiring Diagram Reference

See [system-architecture.md](../02-design/system-architecture.md) for the complete wiring block diagram and interface table.

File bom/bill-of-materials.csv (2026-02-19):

ID | Category | Component | Specification | Qty | Unit | Supplier | Part Number / ASIN / Item | Vendor URL | Unit Cost USD (est) | Total Cost USD (est) | Notes
E01 | Electronics - Control | Microcontroller | ESP32-WROOM-32 38-pin dev board CP2102 USB-UART | 1 | ea | AliExpress | Item 32864722159 | https://www.aliexpress.com/item/32864722159.html | 1.83 | 1.83 | GPIO map: 13/25/26/27=relay; 21/22=I2C; 32/34/35=ADC moisture; 33=float; 16-19/5/17=outputs
E01-ALT | Electronics - Control | Microcontroller (Amazon alt) | ESP32-WROOM-32 38-pin AITRIP 5-pack | 5 | ea | Amazon | B09DPH1KXF | https://www.amazon.com/dp/B09DPH1KXF | 2.60 | 13.00 | ~$2.60/board in 5-pack; CP2102 USB-UART; buy 5 to have spares
E02 | Electronics - Control | RTC module | DS3231 + AT24C32 I2C module with coin cell holder | 1 | ea | AliExpress | Item 4000173986273 | https://www.aliexpress.com/item/4000173986273.html | 2.13 | 2.13 | I2C address 0x68; CR2032 coin cell included; shares I2C bus with OLED
E03 | Electronics - Control | OLED display (optional) | 0.96-inch 128×64 I2C SSD1306 white | 1 | ea | AliExpress | Item 32643950109 | https://www.aliexpress.com/item/32643950109.html | 1.60 | 1.60 | I2C address 0x3C; shares bus with DS3231; GPIO21 SDA / GPIO22 SCL
E04 | Electronics - Power | Buck converter | MP1584EN 12V→5V 3A step-down module — set to 5.00V | 1 | ea | AliExpress | Item 32828603866 | https://www.aliexpress.com/item/32828603866.html | 0.65 | 0.65 | ONLY conversion stage 1 of 2; pre-adjust to 5.00V before connecting ESP32
E05 | Electronics - Power | Fuse holder + fuse | Inline blade fuse holder + 5A automotive blade fuse | 1 | ea | Any hardware | — | — | 1.50 | 1.50 | Protects 12V bus; 5A at 12V = 60W capacity vs 15W peak load
E06 | Electronics - Power | Reverse polarity protection | AO3401 P-channel MOSFET SOT-23 | 1 | ea | AliExpress | AO3401 | — | 0.50 | 0.50 | Source to 12V_in; Drain to fuse; Gate to GND via 10kΩ pull-down
E07 | Electronics - Power | Power input jack | 5.5/2.1mm DC barrel jack panel-mount positive-centre | 1 | ea | AliExpress | — | — | 0.75 | 0.75 | Left outer wall of base unit; positive tip = +12V
E08 | Electronics - Lighting | LED grow strips (primary) | 12V full-spectrum plant grow strip 5050 red+blue+white | 1 | ea | AliExpress | Item 32816538353 | https://www.aliexpress.com/item/32816538353.html | 11.41 | 11.41 | Cut to 3×25cm; fold U-shape per tray; add 10Ω 5W series resistor if >4W; one roll covers all 3 trays
E08-ALT | Electronics - Lighting | LED strips (white alt) | Tesfish 12V 2835 6000K 240LED/m 5m roll | 1 | ea | Amazon | B08T89VRPP | https://www.amazon.com/dp/B08T89VRPP | 10.00 | 10.00 | Alt: cut 3×25cm lengths; 6000K full-spectrum white; 5m roll covers all 3 trays with strip to spare
E08-SLED | Electronics - Lighting | LED panel sled (printed) | led_panel.stl — 100×100mm PETG sled for strip mounting | 3 | ea | Self-print | — | — | — | — | Back with aluminium tape for heat sink; conformal-coat strip for humidity protection
E09 | Electronics - Actuators | Relay module | 4-ch 5V optocoupler hi/lo trigger selectable; JD-VCC isolated | 1 | ea | AliExpress | Item 32897567002 | https://www.aliexpress.com/item/32897567002.html | 3.10 | 3.10 | Set to LOW-level trigger; remove VCC-JD-VCC jumper; power JD-VCC from 5V bus separately
E09-ALT | Electronics - Actuators | Relay module (Amazon alt) | DIYables 4-ch 5V ESP32-compatible hi/lo trigger | 1 | ea | Amazon | B0BXKKYH5C | https://www.amazon.com/dp/B0BXKKYH5C | 10.00 | 10.00 | Explicitly ESP32 3.3V compatible; documented setup guide available
E10 | Electronics - Actuators | Peristaltic pump (primary) | INTLLAB 12V DC peristaltic pump 5-100 mL/min 4-pack | 4 | ea | Amazon | B088TBKNSY | https://www.amazon.com/dp/B088TBKNSY | 6.45 | 25.80 | Use 1; keep 3 spare; 3mm ID × 5mm OD silicone tubing; measures actual flow rate to set run time
E10-ALT | Electronics - Actuators | Peristaltic pump (adjustable alt) | Gikfun EK1971 12V 8-70 mL/min adjustable + 3m tube | 1 | ea | Amazon | B0B4FMSJPV / EK1971 | https://www.amazon.com/dp/B0B4FMSJPV | 18.00 | 18.00 | Adjustable knob for flow rate; includes 3m silicone tube; single pump
E10-ALT2 | Electronics - Actuators | Peristaltic pump (AliExpress alt) | R385 motor 12V peristaltic head | 1 | ea | AliExpress | Item 32770860268 | https://www.aliexpress.com/i/32770860268.html | 5.00 | 5.00 | Budget option; 19-100 mL/min; 3mm ID × 5mm OD tubing; order extra tube
E11 | Electronics - Sensors | Reservoir float switch | ZP2508 mini PP vertical float switch NC (normally closed) | 1 | ea | AliExpress | Item 4000246458661 | https://www.aliexpress.com/item/4000246458661.html | 0.62 | 0.62 | Replaces XKC-Y25-V; NC contact; LOW=low water; install inside reservoir through lid gland; GPIO33 with 10kΩ pull-up
E11-GLAND | Electronics - Sensors | Cable gland for float switch | M5 rubber cable gland Ø3-5mm cable | 1 | ea | AliExpress | — | — | 0.30 | 0.30 | Waterproof float switch wire entry through reservoir lid
E12 | Electronics - Sensors | Temperature sensor (optional) | DS18B20 waterproof probe 1-Wire 3-5V | 1 | ea | AliExpress | DS18B20 | — | 2.00 | 2.00 | Optional; 1-Wire bus; growing chamber temp monitoring; connect to any free GPIO
E13 | Electronics - Sensors | Coir moisture sensor — Tray A | Capacitive Soil Moisture Sensor V1.2 analog 3.3V | 1 | ea | AliExpress | Item 32853373769 | https://www.aliexpress.com/item/32853373769.html | 1.22 | 1.22 | GPIO34 (ADC1_CH6 input-only); VCC=3.3V; calibrate dry-air vs submerged readings
E14 | Electronics - Sensors | Coir moisture sensor — Tray B | Capacitive Soil Moisture Sensor V1.2 analog 3.3V | 1 | ea | AliExpress | Item 32853373769 | https://www.aliexpress.com/item/32853373769.html | 1.22 | 1.22 | GPIO35 (ADC1_CH7 input-only); same calibration procedure as E13
E15 | Electronics - Sensors | Coir moisture sensor — Tray C | Capacitive Soil Moisture Sensor V1.2 analog 3.3V | 1 | ea | AliExpress | Item 32853373769 | https://www.aliexpress.com/item/32853373769.html | 1.22 | 1.22 | GPIO32 (ADC1_CH4); conformal-coat body not tip; insert vertically ~4cm into coir
E15-ALT | Electronics - Sensors | Moisture sensors (Amazon alt 2-pack) | Gikfun EK1940 capacitive corrosion-resistant 2-pack | 2 | ea | Amazon | B07H3P1NRM / EK1940 | https://www.amazon.com/dp/B07H3P1NRM | 4.50 | 9.00 | Buy 2 (= 4 sensors) covers all 3 trays with 1 spare; ~$4.50/2pk
E16 | Electronics - Indicators | Status LED — green 3mm | 3mm green LED 2.1V Vf | 1 | ea | Electronics shop | — | — | 0.10 | 0.10 | GPIO18 via 330Ω; power-on indicator; ~4mA
E17 | Electronics - Indicators | Status LED — yellow 3mm | 3mm yellow LED 2.0V Vf | 1 | ea | Electronics shop | — | — | 0.10 | 0.10 | GPIO19 via 330Ω; reservoir low water alert; ~4mA
E18 | Electronics - Indicators | Status LED — red 3mm (×2) | 3mm red LED 1.8V Vf | 2 | ea | Electronics shop | — | — | 0.10 | 0.20 | GPIO5 (Tray A harvest) and GPIO17 (Tray B+C harvest) each via 330Ω
E19 | Electronics - Indicators | Current-limiting resistors 330Ω | 330Ω 1/4W ±5% through-hole | 10 | ea | Any | — | — | 0.01 | 0.10 | For all 4 status LEDs
E20 | Electronics - Indicators | Buzzer (optional) | 5V active buzzer 85dB 12mm | 1 | ea | AliExpress | — | — | 0.50 | 0.50 | GPIO16 via 100Ω resistor; low-water audible alert
E21 | Electronics - Indicators | Resistor 100Ω | 100Ω 1/4W for buzzer | 1 | ea | Any | — | — | 0.01 | 0.01 | In series with GPIO16 and buzzer
E22 | Electronics - Wiring | Hookup wire — heavy 20 AWG | 20 AWG silicone-insulated red and black 3m each | 6 | m | AliExpress | Item 32980669701 | https://www.aliexpress.com/item/32980669701.html | 0.38 | 2.28 | 12V power runs: LED strips / pump / relay COM / bus; select 20AWG variant
E23 | Electronics - Wiring | Hookup wire — light 24 AWG | 24 AWG silicone multi-colour | 6 | m | AliExpress | Item 32980669701 | https://www.aliexpress.com/item/32980669701.html | 0.38 | 2.28 | Signal wires: GPIO→relay IN / sensors / I2C / LEDs; select 24AWG variant
E24 | Electronics - Wiring | JST-XH connector kit | 230pcs JST XH 2.54mm 2/3/4/5-pin male+female+crimp | 1 | ea | AliExpress | Item 4000410350035 | https://www.aliexpress.com/item/4000410350035.html | 3.18 | 3.18 | Full wiring harness; all inter-module connectors; includes terminals
E25 | Electronics - Wiring | Prototype stripboard | 5×7cm double-sided stripboard | 1 | ea | AliExpress | — | — | 0.75 | 0.75 | Power management board: MP1584 + AO3401 + fuse holder
E26 | Electronics - Wiring | Pin headers male 2.54mm | 40-pin 2.54mm male header strips | 2 | ea | AliExpress | — | — | 0.30 | 0.60 | ESP32 dev board to stripboard; other module mounts
E27 | Electronics - Wiring | Heat shrink tubing | Assorted 2/4/6mm 1m each | 3 | m | AliExpress | — | — | 1.50 | 1.50 | Insulating solder joints and bare wire ends
E28 | Electronics - Wiring | Pull-up resistors 10kΩ | 10kΩ 1/4W through-hole (for float switch and AO3401 gate) | 2 | ea | Any | — | — | 0.01 | 0.02 | 1 for float switch pull-up (GPIO33 to 3.3V); 1 for AO3401 gate pull-down to GND
E29 | Electronics - Wiring | Series resistors 10Ω 5W | 10Ω 5W wirewound resistor (LED strip current limit) | 3 | ea | Any | — | — | 0.30 | 0.90 | One per LED strip if using 60cm of 5050 strip (limits to ~3W); omit if using 25cm cuts
H01 | Hardware - Fasteners | M3×20mm bolts | Stainless steel pan-head Phillips | 60 | ea | Any hardware | — | — | 0.05 | 3.00 | Base halves + ring stacks + ring quarter seams
H02 | Hardware - Fasteners | M3 hex nuts | Stainless steel | 60 | ea | Any hardware | — | — | 0.03 | 1.80 | Captured nut pockets throughout
H03 | Hardware - Fasteners | M3×10mm bolts | Stainless steel pan-head | 20 | ea | Any hardware | — | — | 0.04 | 0.80 | Door hinges + LED brackets + misc
H04 | Hardware - Fasteners | M5 heat-set inserts | OD 7mm depth 8mm brass | 4 | ea | AliExpress / Amazon | — | — | 0.30 | 1.20 | Vehicle mounting corners in base underside
H05 | Hardware - Fasteners | Hinge pins | 3mm steel rod cut to length or M3×30mm bolts | 3 | ea | Any hardware | — | — | 0.20 | 0.60 | Front door hinges (1 pin per door × 3 doors)
H06 | Hardware - Sealing | RTV silicone sealant | Neutral-cure clear food-safe 80mL tube | 1 | ea | Hardware store | — | — | 6.00 | 6.00 | Base split joint + ring quarter seams + reservoir lid gland
H07 | Hardware - Sealing | Foam weather-strip | 3mm closed-cell self-adhesive 5m roll | 1 | ea | Hardware / Amazon | — | — | 4.00 | 4.00 | Ring flange light-seal + door perimeter seal
H08 | Hardware - Sealing | O-ring | Ø40mm ID × 2mm cross-section | 1 | ea | Hardware / Amazon | — | — | 0.50 | 0.50 | Reservoir fill port lid seal
H09 | Hardware - Sealing | Neodymium magnets | Ø8mm × 3.5mm disc | 6 | ea | AliExpress / Amazon | — | — | 0.40 | 2.40 | 2 per door (ring pocket + door pocket) × 3 doors
H10 | Hardware - Sealing | CA glue (super glue) | 5g tube | 1 | ea | Any | — | — | 1.00 | 1.00 | Securing magnets after polarity verification
P01 | Printed - Base | Base front half | base_front.stl PETG 40% infill | 1 | ea | Self-print | — | — | — | — | 280g / 8h
P02 | Printed - Base | Base rear half | base_rear.stl PETG 40% infill | 1 | ea | Self-print | — | — | — | — | 250g / 7h; reservoir + electronics bay
P03 | Printed - Base | Reservoir lid | reservoir_lid.stl PETG 40% infill + 5mm hole for float switch gland | 1 | ea | Self-print | — | — | — | — | 30g / 1h; add M5 gland port for ZP2508 float switch wires
P04 | Printed - Base | Waste chamber lid | waste_lid.stl PETG 40% infill | 1 | ea | Self-print | — | — | — | — | 20g / 0.75h; snap-fit
P05 | Printed - Base | Electronics bay cover | electronics_cover.stl PETG 30% infill | 1 | ea | Self-print | — | — | — | — | 25g / 0.75h; cable pass-through slot
P06 | Printed - Base | Pump mount bracket | pump_mount.stl PETG 40% infill | 1 | ea | Self-print | — | — | — | — | 15g / 0.5h
P07 | Printed - Ring | Ring FL quarter (×3 sets) | ring_FL.stl PETG 30% infill | 3 | ea | Self-print | — | — | — | — | 120g each / 3.5h
P08 | Printed - Ring | Ring FR quarter (×3 sets) | ring_FR.stl PETG 30% infill | 3 | ea | Self-print | — | — | — | — | 110g each / 3h
P09 | Printed - Ring | Ring RL quarter (×3 sets) | ring_RL.stl PETG 30% infill | 3 | ea | Self-print | — | — | — | — | 80g each / 2h
P10 | Printed - Ring | Ring RR quarter (×3 sets) | ring_RR.stl PETG 30% infill | 3 | ea | Self-print | — | — | — | — | 80g each / 2h
P11 | Printed - Trays | Growing tray | growing_tray.stl PETG 30% infill | 3 | ea | Self-print | — | — | — | — | 60g each / 2h; 4×Ø8mm drain holes
P12 | Printed - Trays | Sub-tray | sub_tray.stl PETG 40% infill | 3 | ea | Self-print | — | — | — | — | 50g each / 1.5h; WATERPROOF COAT REQUIRED
P13 | Printed - Lighting | LED bracket | led_bracket.stl PETG 30% infill | 3 | ea | Self-print | — | — | — | — | 20g each / 0.5h; ±15mm height adjustment
P14 | Printed - Doors | Front door | tray_door.stl PETG 20% infill | 3 | ea | Self-print | — | — | — | — | 30g each / 1h
P15 | Printed - Cap | Top cap body | top_cap.stl PETG 25% infill | 1 | ea | Self-print | — | — | — | — | 80g / 2.5h
P16 | Printed - Cap | Seed box lid | seed_box_lid.stl PETG 25% infill | 1 | ea | Self-print | — | — | — | — | 15g / 0.5h
P17 | Printed - Misc | Tube saddle clips | tube_clip.stl PETG 50% infill | 12 | ea | Self-print | — | — | — | — | 5g each / 0.25h
P18 | Printed - Misc | 3-way water manifold | manifold_3way.stl PETG 60% infill | 1 | ea | Self-print | — | — | — | — | 10g / 0.5h
P19 | Printed - Misc | Drip emitter cap | drip_emitter.stl PETG 60% infill | 3 | ea | Self-print | — | — | — | — | 3g each / 0.25h; 2mm orifice
P20 | Printed - Misc | Status LED panel | led_panel.stl PETG 25% infill | 1 | ea | Self-print | — | — | — | — | 10g / 0.3h; 4× 3mm LED mount in top cap
F01 | Filament | PETG filament 1.75mm | Food-safe grade preferred; any colour | 2.5 | kg | Filament supplier | — | — | 22.00 | 55.00 | ~2465g total; buy 3kg spool
W01 | Waterproofing | XTC-3D epoxy coating | Smooth-On XTC-3D 2-part epoxy | 1 | ea | Smooth-On / Amazon | — | — | 18.00 | 18.00 | Reservoir / waste chamber / sub-tray interiors; critical
W02 | Waterproofing | Rustoleum Crystal Clear (alternative) | Spray lacquer 3-4 coats | 1 | ea | Hardware store | — | — | 10.00 | 10.00 | Alternative to W01
C01 | Consumable - Seeds | Broccoli microgreen seed | Untreated non-GMO De Cicco / Calabrese / Waltham 29 | 500 | g | True Leaf Market / Johnny's Seeds | — | — | 15.00 | 15.00 | ~500g lasts ~5 months
C02 | Consumable - Medium | Compressed coir pucks | 50g compressed 100% coir | 24 | ea | Amazon / Garden centre | — | — | 0.75 | 18.00 | ~6/month; 24 = 4-month supply
C03 | Consumable - Supplement | CalMag liquid (optional) | General Hydroponics CALiMAGic 240mL | 1 | ea | Hydroponic store / Amazon | — | — | 12.00 | 12.00 | Optional; 0.5mL/L from day 3; 240mL lasts ~8 months
C04 | Consumable - Storage | Small zip-lock bags | 10×8cm food-grade resealable 100-pack | 100 | ea | Amazon / Dollar store | — | — | 4.00 | 4.00 | ~15/month for frozen 30g portions
S01 | Solar - Optional | Solar panel | 40W monocrystalline 12V | 1 | ea | Amazon / eBay | — | — | 38.00 | 38.00 | Off-grid; 40W × 4PSH × 0.85 = 136 Wh/day vs ~159 Wh/day avg — consider 50W for margin
S02 | Solar - Optional | MPPT charge controller | 10A 12V/24V auto | 1 | ea | AliExpress / Amazon | — | — | 20.00 | 20.00 | Off-grid only
S03 | Solar - Optional | LiFePO4 battery | 12V 20Ah with built-in BMS | 1 | ea | Amazon | — | — | 58.00 | 58.00 | ~34h autonomy on battery alone
S04 | Solar - Optional | Solar cable + MC4 connectors | 10AWG 3m pair | 1 | ea | Amazon | — | — | 8.00 | 8.00 | Off-grid only
S05 | Solar - Optional | Battery cable + Anderson PP45 | 10AWG 1m pair | 1 | ea | Amazon | — | — | 6.00 | 6.00 | Off-grid only
E30 | Electronics - Ventilation | 40mm 12V brushless fan | 40×40×10mm 12V DC 2-pin brushless PC fan ≤25 dBA | 1 | ea | AliExpress / Amazon | — | — | 3.00 | 3.00 | Top cap exhaust fan; label/inlet side faces INTO cap; DECISION-024
E31 | Electronics - Ventilation | SPST mini toggle switch | Panel-mount toggle 6mm body 12V DC rated ON-OFF | 1 | ea | AliExpress / Electronics shop | — | — | 1.00 | 1.00 | 6.5mm panel-cut hole in top cap front face (right side); wired 12V → switch → fan; no relay or firmware
E32 | Electronics - Ventilation | 40mm fan guard/grill | Plastic or wire snap-fit fan guard for 40mm fans | 1 | ea | AliExpress | — | — | 0.50 | 0.50 | Snap onto fan exterior face to prevent blade contact
E33 | Enclosure - Insect Protection | 40mm PC fan dust filter | Foam or fine-mesh snap-fit dust filter for 40mm fan frames ≤0.5mm pore size | 1 | ea | AliExpress / Amazon | — | — | 1.50 | 1.50 | Slides under fan guard on fan exterior (exhaust) face; blocks fungus gnats and other insects from entering column through fan hole when fan is off; DECISION-024
E34 | Enclosure - Insect Protection | Fiberglass insect screen mesh | Fine fiberglass window screen ~1.2mm pore — 100×50mm piece (cut 6× 27×10mm patches) | 1 | ea | Hardware store / Amazon | — | — | 1.00 | 1.00 | Adhere one patch over interior of each ring vent slot opening with RTV silicone (6 patches total: 2 slots × 3 rings); permanent insect barrier; slide cover still functions over mesh for light sealing

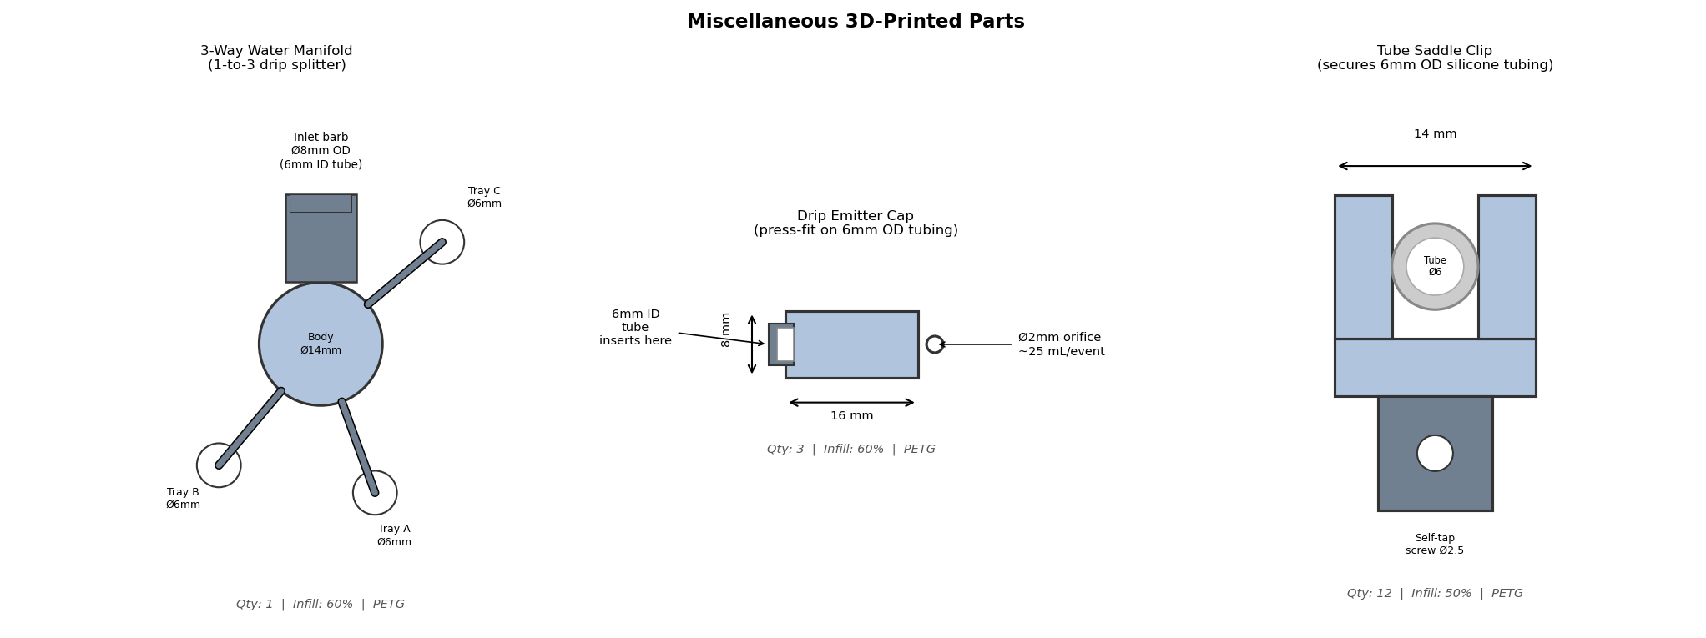
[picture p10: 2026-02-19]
hardware/3d-models/renders/09_misc_parts.png

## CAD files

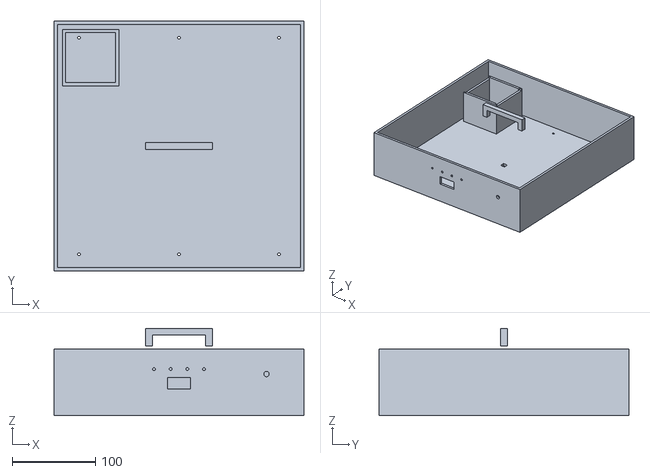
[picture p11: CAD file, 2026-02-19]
hardware/3d-models/stl/top_cap.stl
300.0 x 300.0 x 105.0

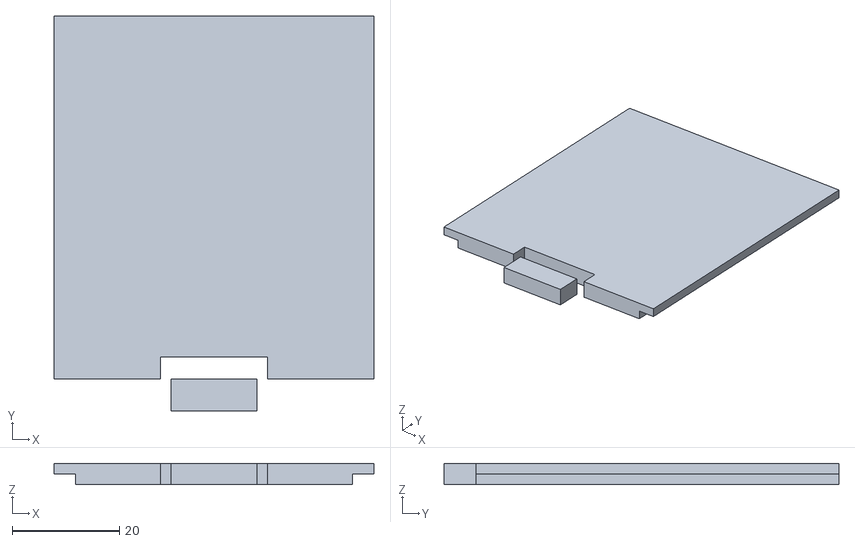
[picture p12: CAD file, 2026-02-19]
hardware/3d-models/stl/seed_box_lid.stl
59.5 x 73.5 x 4.00

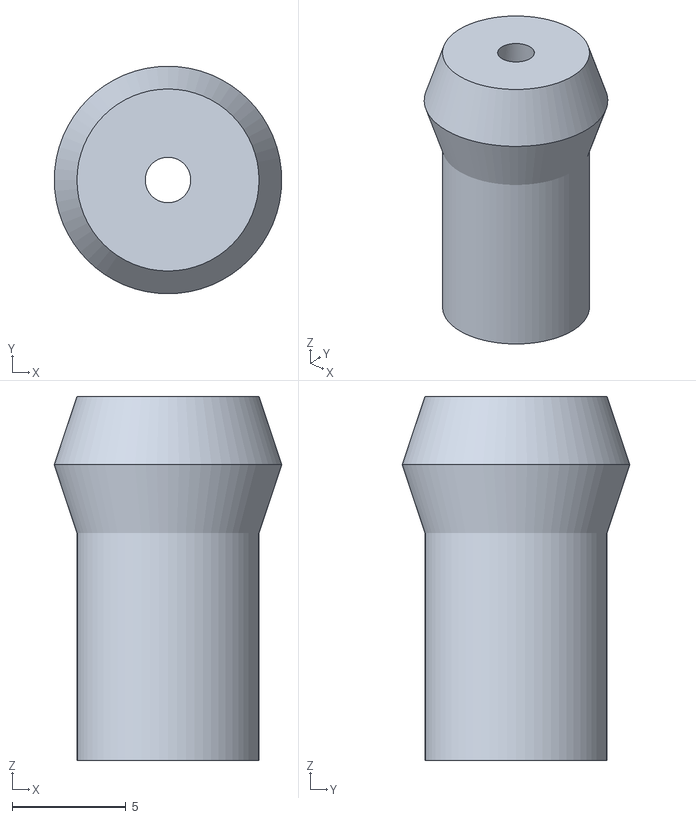
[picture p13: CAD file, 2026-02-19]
hardware/3d-models/stl/drip_emitter.stl
10.0 x 10.0 x 16.0

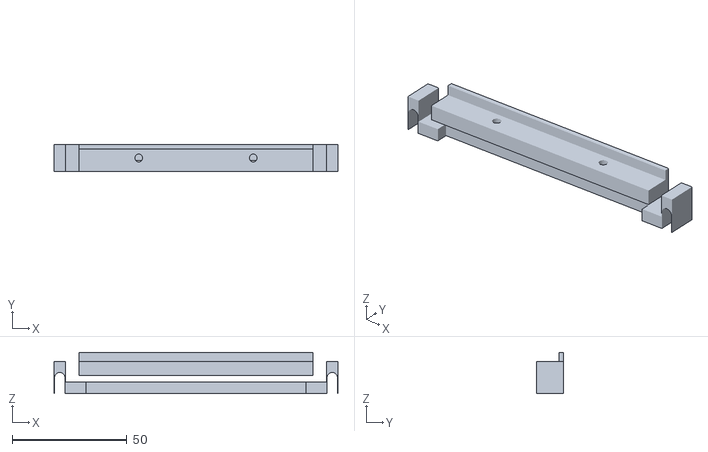
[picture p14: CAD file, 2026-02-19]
hardware/3d-models/stl/led_bracket.stl
124.0 x 12.0 x 18.0

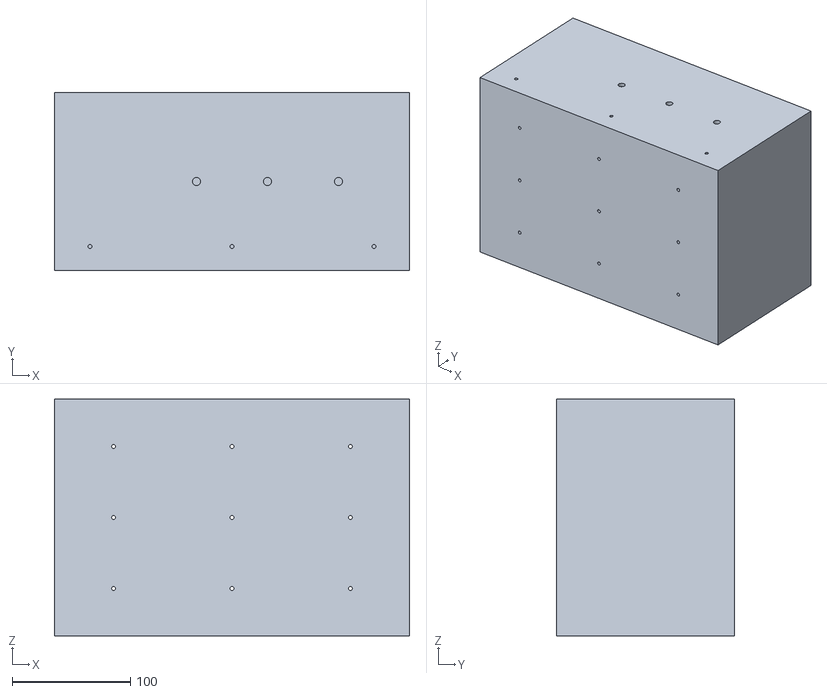
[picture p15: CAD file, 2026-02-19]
hardware/3d-models/stl/base_front.stl
300.0 x 150.0 x 200.0

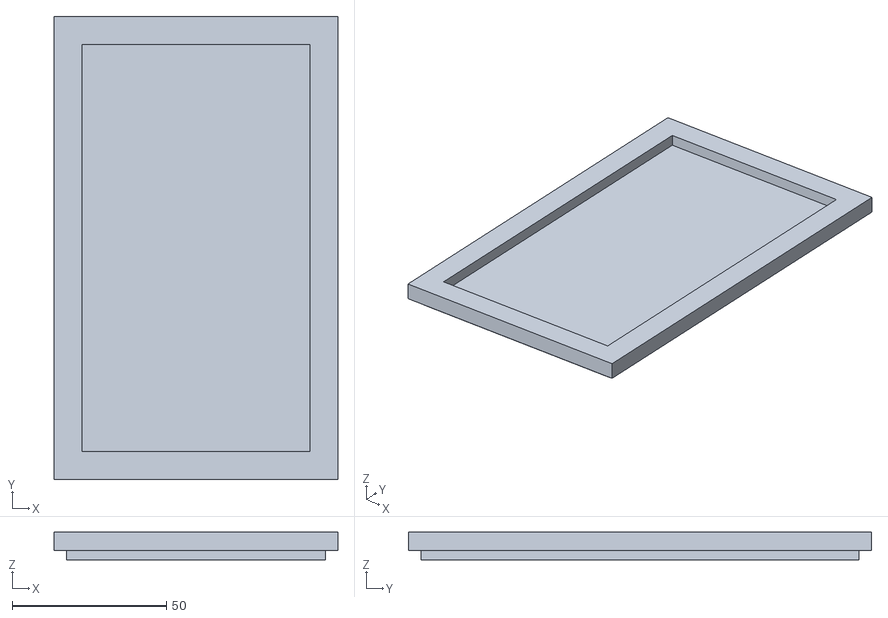
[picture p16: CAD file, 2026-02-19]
hardware/3d-models/stl/waste_lid.stl
92.0 x 150.0 x 9.00

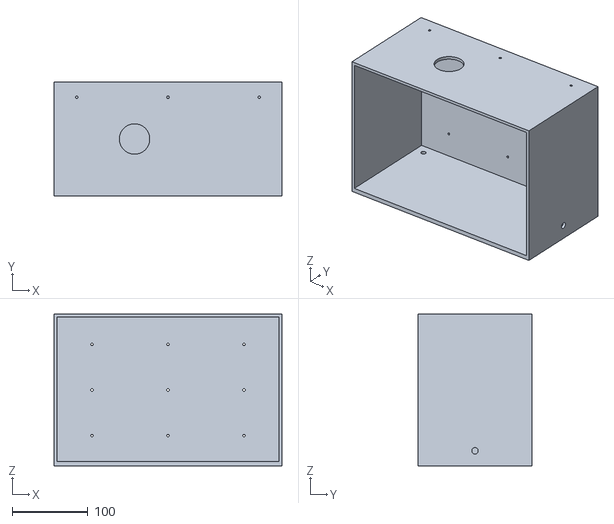
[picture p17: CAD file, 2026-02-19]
hardware/3d-models/stl/base_rear.stl
300.0 x 150.0 x 200.0

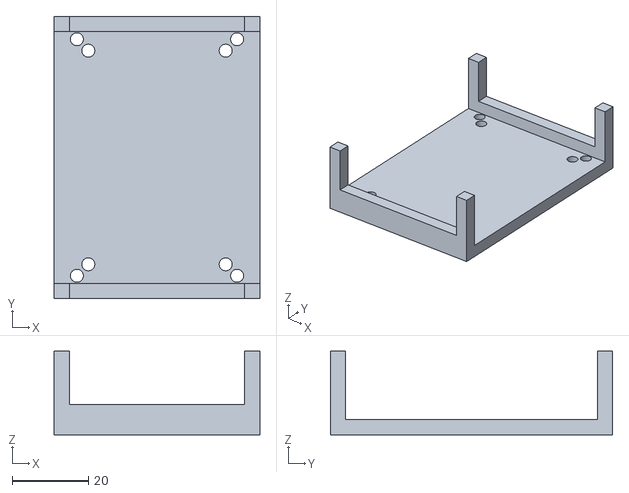
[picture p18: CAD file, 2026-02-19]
hardware/3d-models/stl/pump_mount.stl
54.0 x 74.0 x 22.0

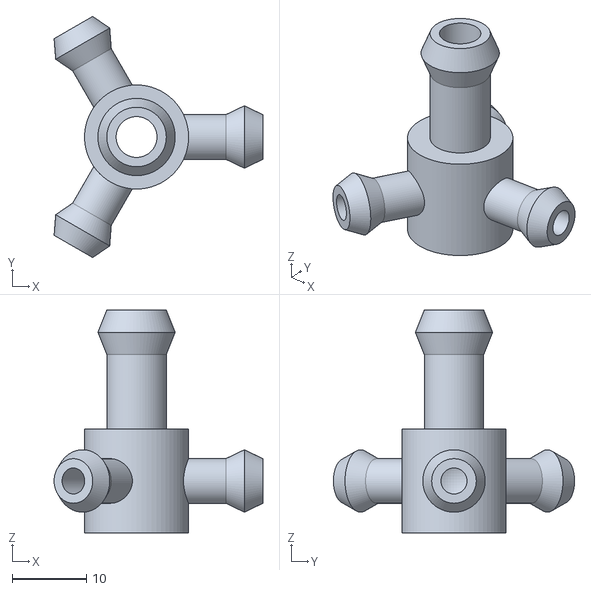
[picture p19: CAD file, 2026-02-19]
hardware/3d-models/stl/manifold_3way.stl
28.1 x 32.4 x 30.0

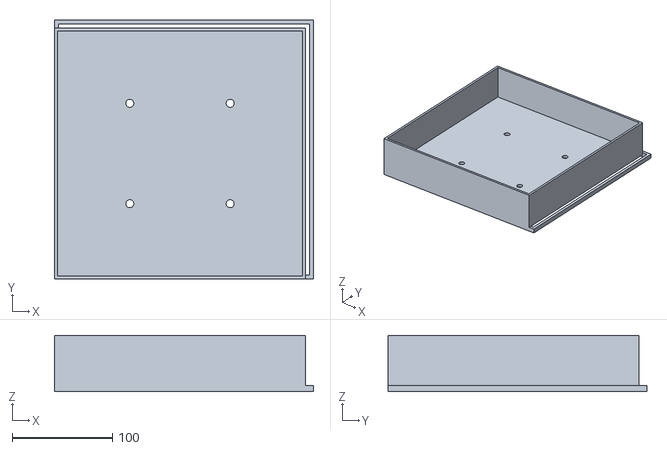
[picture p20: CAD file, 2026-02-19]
hardware/3d-models/stl/growing_tray.stl
258.0 x 258.0 x 56.0

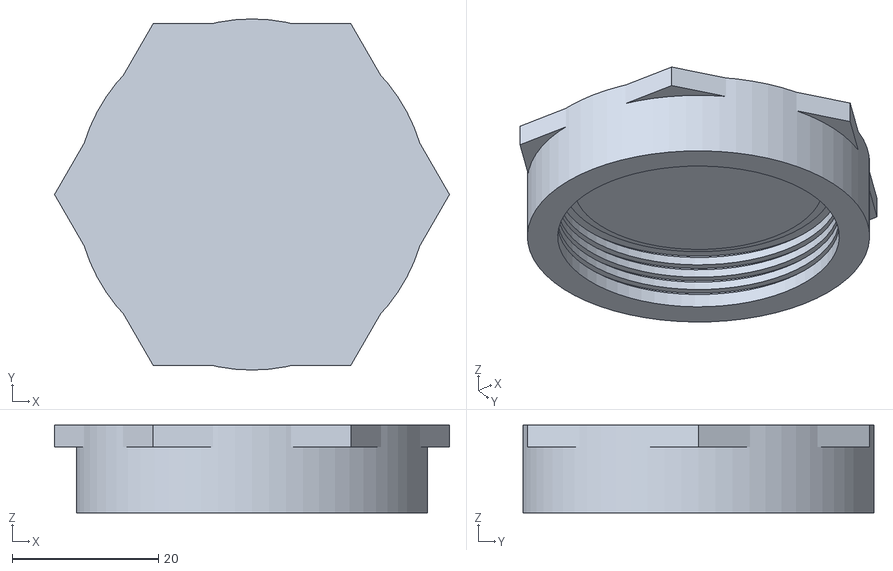
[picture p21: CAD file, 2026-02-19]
hardware/3d-models/stl/reservoir_lid.stl
54.0 x 48.0 x 12.0

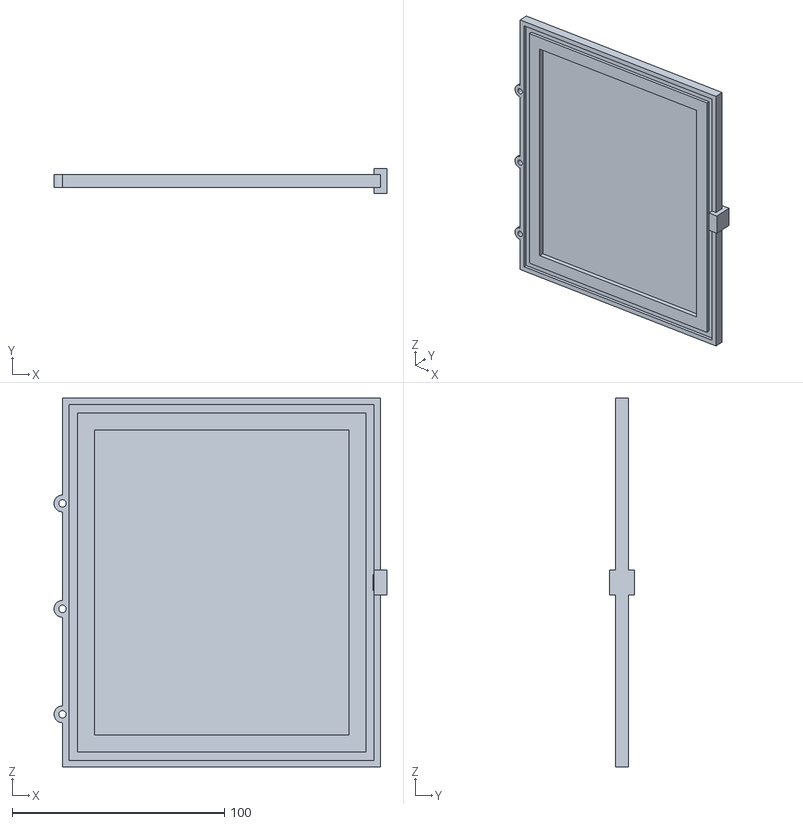
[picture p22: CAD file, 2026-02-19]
hardware/3d-models/stl/tray_door.stl
157.0 x 12.0 x 174.0

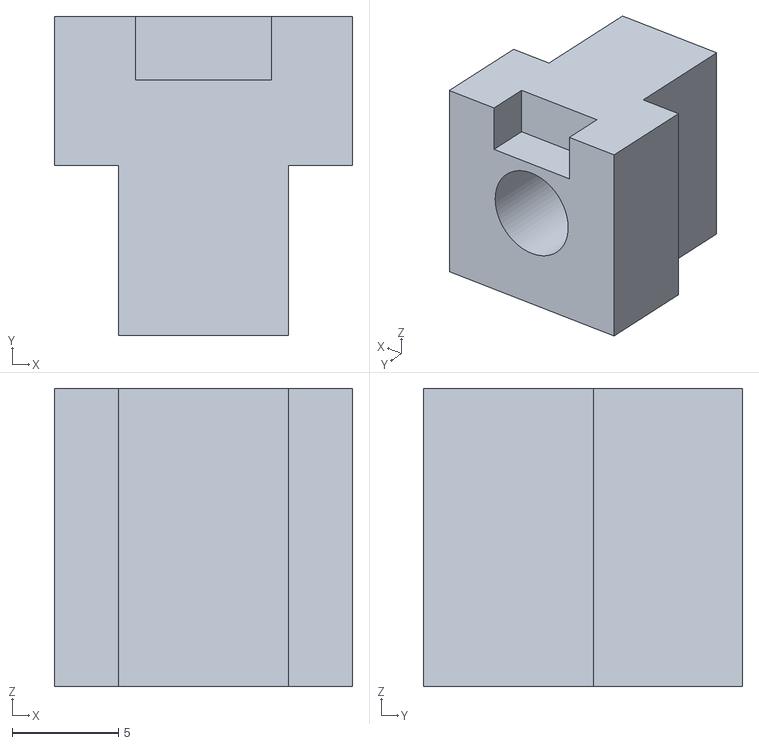
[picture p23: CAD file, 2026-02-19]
hardware/3d-models/stl/tube_clip.stl
14.0 x 15.0 x 14.0

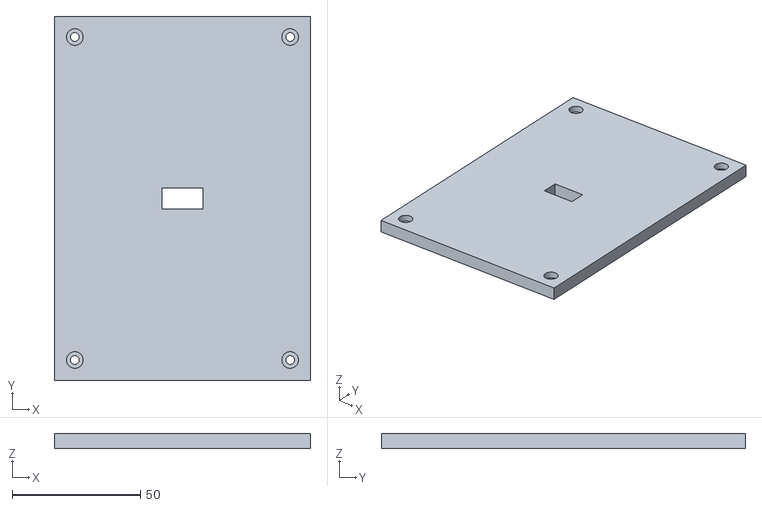
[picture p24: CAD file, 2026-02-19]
hardware/3d-models/stl/electronics_cover.stl
100.0 x 142.0 x 6.00

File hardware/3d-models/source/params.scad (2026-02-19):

// ============================================================
// Microgreen Box — Master Parameters
// ============================================================
// Source of truth for all 3D model dimensions.
// All values derived from:
//   PROJECT_DECISIONS.md
//   docs/02-design/enclosure-design.md
//   docs/02-design/watering-system.md
//   docs/02-design/growing-system.md
//   docs/02-design/lighting-system.md
//
// DECISION-012: PETG mandatory for all structural and water-contact parts.
// DECISION-007: Coir growing medium (NOT compost).
// DECISION-011: Fully sealed water paths, peristaltic pump.
// DECISION-009: 12V DC primary power.
//
// Key design constraints (from PROJECT_DECISIONS.md §Constraints):
//   C-006: Enclosure footprint ≤35×35cm
//   C-007: Reservoir ≥1.5L (2L chosen)
//   C-012: All parts print on ≤200×200mm bed
//
// Total height: base_h + 3*ring_h + cap_h = 200+3*190+80 = 850mm ✓
// ============================================================

// ---- Render quality ----------------------------------------
// Increase $fn for production STLs (slower render, better circles)
$fn = 48;

// ---- Global tolerances & fit types -------------------------
tol        = 0.20;   // Clearance fit (moving parts) [mm]
press_tol  = 0.05;   // Press fit (permanent joints) [mm]
eps        = 0.01;   // Anti-z-fight epsilon [mm]

// ---- Wall & structure --------------------------------------
enc_wall   = 4.0;    // Outer wall thickness [mm]
floor_t    = 6.0;    // Floor / ceiling thickness [mm]
flange_h   = 8.0;    // Stack-join flange height [mm]
seal_lip   = 2.0;    // Light-seal inward lip depth [mm]

// ---- Fasteners: M3 (ring stacking, panel assembly) ---------
m3_clr     = 3.4;    // M3 clearance hole diameter [mm]
m3_head_d  = 6.5;    // M3 pan-head OD [mm]
m3_head_h  = 3.0;    // M3 pan-head height [mm]
m3_nut_w   = 6.1;    // M3 hex nut across-flats [mm]
m3_nut_h   = 2.5;    // M3 hex nut height [mm]
m3_boss_d  = 7.0;    // Boss OD around M3 hole [mm]

// ---- Fasteners: M5 heat-set inserts (vehicle mounting) -----
// DECISION-012: 4× M5 inserts in base corners for strap/bracket attachment
m5_ins_od  = 7.0;    // M5 heat-set insert outer diameter [mm]
m5_ins_h   = 8.0;    // M5 heat-set insert depth [mm]
m5_corner  = 18.0;   // Insert centre distance from outer corner [mm]

// ============================================================
// ENCLOSURE GLOBAL FOOTPRINT (enclosure-design.md)
// ============================================================
enc_w      = 300.0;  // Outer width  (X) [mm]
enc_d      = 300.0;  // Outer depth  (Y) [mm]

enc_int_w  = enc_w - 2*enc_wall;  // Interior clear width  = 292mm
enc_int_d  = enc_d - 2*enc_wall;  // Interior clear depth  = 292mm

// ============================================================
// BASE UNIT  (enclosure-design.md §Base Unit)
// Outer: 300×300×200mm
// Split front/rear at Y=150 for printing.
// Print halves standing on the 150×200mm (YZ) face.
// Minimum bed: 200mm wide (X) × 150mm deep (Y), part 200mm tall (Z).
// ============================================================
base_h      = 200.0;   // Base unit outer height [mm]
base_split  = 150.0;   // Front/rear split Y position [mm]

// Chamber interior height (floor_t=6 → floor_t+ch_h=90mm → ceiling at 90mm)
ch_h        = 84.0;    // Interior height of sealed chambers [mm]

// --- Reservoir (rear-left, DECISION-011) --------------------
// Interior: X=4..208, Y=154..296, Z=6..90
// Volume: 204 × 142 × 84 ≈ 2.43L  ✓  (≥2L spec)
res_x1      = enc_wall;        // Inner left edge  [mm]
res_x2      = 208.0;           // Inner right edge [mm]  (204mm wide)
res_y1      = base_split + enc_wall;  // Inner front edge [mm]
res_y2      = enc_d - enc_wall;       // Inner rear edge  [mm]  (296mm)

// --- Waste chamber (rear-right, adjacent to reservoir) -------
// Interior: X=212..296, Y=154..296, Z=6..90
// Volume: 84 × 142 × 84 ≈ 1.00L  ✓  (≥500mL spec)
waste_x1    = res_x2 + enc_wall;        // Inner left edge  [mm]
waste_x2    = enc_d - enc_wall;         // Inner right edge [mm]

// --- Electronics bay (front-left, DECISION-008) --------------
// Interior: X=4..104, Y=4..146, Z=6..90
elec_x1     = enc_wall;          // Inner left edge  [mm]
elec_x2     = 104.0;             // Inner right edge [mm]
elec_y1     = enc_wall;          // Inner front edge [mm]
elec_y2     = base_split - enc_wall;    // Inner rear edge  [mm]

// --- Pump / wiring space (front-right, open top) ------------
// X=108..296, Y=4..146 — accessible from top; no lid required

// --- Fill port (top-access screw cap over reservoir) --------
fill_d      = 40.0;   // Fill port inner diameter (O-ring groove) [mm]
fill_boss_d = fill_d + 8.0;  // Boss outer diameter [mm]
fill_boss_h = 14.0;   // Boss height above top face [mm]
fill_oring  = 2.0;    // O-ring groove depth [mm]
// Fill port centre position
fill_x      = (res_x1 + res_x2) / 2;   // = 106mm
fill_y      = (res_y1 + res_y2) / 2;   // = 225mm

// --- Power jack aperture (left wall, side-mount) ------------
// 5.5/2.1mm barrel jack, DECISION-009
jack_hole_d = 12.0;   // Panel cutout diameter [mm]
jack_y      = 60.0;   // Jack centre, Y from front [mm]
jack_z      = 130.0;  // Jack centre, Z from base bottom [mm]

// --- Stack bolt holes (top face → ring attaches here) -------
// 6× M3 holes: 2 rows of 3 at X=30/150/270, Y=20 and Y=280
ring_bolt_xs = [30, 150, 270];   // X positions [mm]
ring_bolt_y1 = 20.0;             // Front bolt row Y [mm]
ring_bolt_y2 = enc_d - 20.0;    // Rear bolt row Y  [mm]

// --- Waste overflow port (rear wall, tubing exit) -----------
waste_port_d = 8.5;   // Hole diameter (fits 6mm OD tube + sealant) [mm]
waste_port_z = 20.0;  // Z height from base bottom [mm]

// ============================================================
// TRAY RING  (enclosure-design.md §Tray Level Ring)
// Outer: 300×300×190mm per level  (×3 required)
// NOTE: Design doc states 260mm; 190mm used here so
//       total = 200 + 3×190 + 80 = 850mm ≤ 900mm NFR.
//       Override ring_h=260 for extra LED headroom (total 1060mm).
//
// Split into 4 corner-quarter sections for 200×200mm beds:
//   FL (front-left), FR (front-right), RL (rear-left), RR (rear-right)
// Each quarter ≈150×150×ring_h — fits on 200×200mm bed,
// printed standing up (ring_h in Z, ~190mm ≤ 200mm build height).
// ============================================================
ring_h      = 190.0;  // Ring outer height per level [mm]
ring_split_x = enc_w / 2;   // Corner-quarter split X = 150mm
ring_split_y = enc_d / 2;   // Corner-quarter split Y = 150mm

// --- Tray ledge rails (left+right inner walls only) ---------
ledge_w     = 6.0;   // Ledge width (protrusion from inner wall) [mm]
ledge_t     = 4.0;   // Ledge thickness (Z) [mm]
sub_ledge_z = 12.0;  // Sub-tray ledge Z above ring floor [mm]
grow_ledge_z = sub_ledge_z + 40.0 + ledge_t;  // Growing tray ledge Z [mm]
                     // = 12 + 40 + 4 = 56mm

// --- Drip inlet port (rear wall) ----------------------------
drip_port_d = 8.0;   // Drip tube port hole OD [mm]
drip_port_x = enc_w / 2;   // Centred horizontally [mm]
drip_port_z = grow_ledge_z + 60.0;  // Above tray surface [mm]

// --- Front door aperture ------------------------------------
// DECISION-012: hinged PETG door with magnetic catch
door_w      = 150.0;  // Door opening width [mm]
door_x0     = (enc_w - door_w) / 2;  // Aperture left edge X = 75mm
door_h_open = ring_h - 2*flange_h;   // Aperture height [mm]
door_z0     = flange_h;               // Aperture bottom Z [mm]

// Door hinge (left edge of aperture)
hinge_d     = 3.5;   // Hinge pin hole diameter [mm]
hinge_boss  = 8.0;   // Hinge boss OD [mm]
hinge_count = 3;     // Number of hinge knuckles

// Door catch magnet (right edge of aperture, mid-height)
magnet_d    = 8.0;   // Magnet OD [mm]
magnet_dep  = 3.5;   // Magnet pocket depth [mm]

// --- LED wire pass-through (front wall, above door) ---------
led_wire_w  = 8.0;   // Wire slot width [mm]
led_wire_h  = 6.0;   // Wire slot height [mm]
led_wire_x  = enc_w - 30.0;  // Slot centre X [mm]
led_wire_z  = ring_h - flange_h - 15.0;  // Slot centre Z [mm]

// --- Ring stack bolt holes (M3, top and bottom flanges) -----
// Same X positions as base unit: ring_bolt_xs = [30, 150, 270]
// Y positions: front row at 20, rear row at 280
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

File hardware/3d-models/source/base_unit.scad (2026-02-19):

// ============================================================
// Base Unit
// ============================================================
// Outer: 300×300×200mm
// Contains:
//   - Water reservoir (~2.43L, rear-left)
//   - Waste chamber (~1.0L, rear-right)
//   - Electronics bay (~1.2L, front-left)
//   - Pump/wiring space (front-right, open top)
//
// PART variable selects what to render:
//   "full"      — complete assembled base (reference model)
//   "front"     — front half (Y=0..150) for printing
//   "rear"      — rear half (Y=150..300) for printing
//   "lid_res"   — reservoir screw-cap lid
//   "lid_waste" — waste chamber lid
//   "elec_cov"  — electronics bay cover panel
//   "pump_mnt"  — peristaltic pump mount bracket
//
// Print orientation (base halves):
//   Stand on the 150×200mm (Y×Z) face.
//   Footprint on bed: 300mm (X) × 150mm (Y).
//   Build height: 200mm (Z).
//   Minimum bed: 300mm wide × 150mm deep.
//   NOTE: A 300mm bed dimension is required; the 200×200mm
//   minimum stated in printing-instructions.md is insufficient
//   for base halves unless parts are split further into quarters.
//
// Assembly:
//   6× M3×20mm bolts + nuts at split face (Y=150).
//   RTV silicone bead on water-zone seam before bolting.
//   PETG solvent weld (MEK) on electronics bay seam (optional).
// ============================================================

include <params.scad>

PART = "full";   // Override with: openscad -D 'PART="front"' ...

// ------------------------------------------------------------
// MODULE: complete base unit geometry
// ------------------------------------------------------------
module base_unit_geo() {
    difference() {

        // --- Outer shell ---
        cube([enc_w, enc_d, base_h]);

        // --- Main interior void ---
        // Keeps 4mm walls, 6mm floor, 4mm top shelf
        translate([enc_wall, enc_wall, floor_t])
            cube([enc_int_w, enc_int_d, base_h - floor_t - enc_wall + eps]);

        // --- Reservoir cavity (rear-left) ---
        // Interior: 204mm × 142mm × 84mm ≈ 2.43L
        translate([res_x1, res_y1, floor_t])
            cube([res_x2 - res_x1, res_y2 - res_y1, ch_h + eps]);

        // --- Waste chamber cavity (rear-right) ---
        // Interior: 84mm × 142mm × 84mm ≈ 1.00L
        translate([waste_x1, res_y1, floor_t])
            cube([waste_x2 - waste_x1, res_y2 - res_y1, ch_h + eps]);

        // --- Electronics bay cavity (front-left) ---
        // Interior: 100mm × 142mm × 84mm ≈ 1.19L
        translate([elec_x1, elec_y1, floor_t])
            cube([elec_x2 - elec_x1, elec_y2 - elec_y1, ch_h + eps]);

        // --- Power jack aperture (left outer wall, X=0 face) ---
        // 5.5/2.1mm barrel jack, positive-centre, DECISION-009
        translate([-eps, jack_y, jack_z])
            rotate([0, 90, 0])
                cylinder(d=jack_hole_d, h=enc_wall + 2*eps);

        // --- Reservoir fill port (through top surface) ---
        translate([fill_x, fill_y, base_h - enc_wall - eps])
            cylinder(d=fill_d, h=enc_wall + fill_boss_h + 2*eps);

        // --- Stack bolt holes: 6× M3 through top face ---
        // For attaching tray ring 1 to base top
        for (bx = ring_bolt_xs) {
            translate([bx, ring_bolt_y1, base_h - enc_wall - eps])
                cylinder(d=m3_clr, h=enc_wall + 2*eps);
            translate([bx, ring_bolt_y2, base_h - enc_wall - eps])
                cylinder(d=m3_clr, h=enc_wall + 2*eps);
        }

        // --- M5 heat-set insert recesses (base underside, 4 corners) ---
        // Vehicle mounting points, DECISION-012
        for (cx = [m5_corner, enc_w - m5_corner])
            for (cy = [m5_corner, enc_d - m5_corner])
                translate([cx, cy, -eps])
                    cylinder(d=m5_ins_od, h=m5_ins_h + eps);

        // --- Pump tubing outlet holes (top, 3× for tray supply lines) ---
        // Positioned above pump/wiring space (front-right quadrant)
        for (i = [0:2])
            translate([120 + i * 60, base_split/2, base_h - enc_wall - eps])
                cylinder(d=7.0, h=enc_wall + 2*eps);

        // --- Waste overflow port (rear wall, connects to external drain) ---
        // Ø8.5mm for 6mm OD tubing + silicone sealant
        translate([enc_w - enc_wall - eps,
                   (res_y1 + res_y2)/2,
                   waste_port_z])
            rotate([0, 90, 0])
                cylinder(d=waste_port_d, h=enc_wall + 2*eps);

        // --- Split face bolt holes: 3× M3 at Y=base_split ---
        // Through the full base height at the split plane
        // Bolts go in Y-direction; heads at Y=0 (front face)
        for (bx = [50, 150, 250]) {
            translate([bx, -eps, 40])
                rotate([-90, 0, 0])
                    cylinder(d=m3_clr, h=base_d_half() + 2*eps);
            translate([bx, -eps, 100])
                rotate([-90, 0, 0])
                    cylinder(d=m3_clr, h=base_d_half() + 2*eps);
            translate([bx, -eps, 160])
                rotate([-90, 0, 0])
                    cylinder(d=m3_clr, h=base_d_half() + 2*eps);
        }

        // --- Water level sensor flat spot (left outer wall) ---
        // XKC-Y25-V capacitive sensor mounts on exterior of reservoir wall
        // Flatten area: X=0..0.5mm, Y=res_y1..res_y1+40, Z=floor_t..floor_t+40
        translate([-eps, res_y1 + 20, floor_t + 10])
            cube([enc_wall * 0.4, 40, 40]);

    } // end difference

    // --- Fill port boss (raised collar above top face) ---
    difference() {
        union() {
            translate([fill_x, fill_y, base_h - enc_wall])
                cylinder(d=fill_boss_d, h=fill_boss_h);
            // Hex flat for wrench grip (optional — comment out if not needed)
            translate([fill_x, fill_y, base_h - enc_wall + fill_boss_h - 6])
                cylinder(d=fill_boss_d + 2, h=6, $fn=6);
        }
        // Bore through boss
        translate([fill_x, fill_y, base_h - enc_wall - eps])
            cylinder(d=fill_d, h=fill_boss_h + 2*eps);
        // O-ring groove (2mm wide × 2mm deep, at mid-boss height)
        translate([fill_x, fill_y, base_h - enc_wall + 5])
            difference() {
                cylinder(d=fill_d + 4*fill_oring, h=fill_oring + 1);
                cylinder(d=fill_d,                h=fill_oring + 2);
            }
    }

    // --- Electronics bay cover ledge / lip ---
    // A 4mm-wide shelf inside the electronics bay top edge
    // electronics_cover.stl rests on this lip
    translate([elec_x1, elec_y1, floor_t + ch_h])
        difference() {
            cube([elec_x2 - elec_x1, elec_y2 - elec_y1, enc_wall]);
            translate([enc_wall, enc_wall, -eps])
                cube([elec_x2 - elec_x1 - 2*enc_wall,
                      elec_y2 - elec_y1 - 2*enc_wall,
                      enc_wall + 2*eps]);
        }

} // end base_unit_geo

// Helper: half-depth for bolt hole through-length
function base_d_half() = enc_d;   // bolts span full depth; nut captures at other half

// ------------------------------------------------------------
// MODULE: reservoir screw-cap lid (reservoir_lid.stl)
// ------------------------------------------------------------
module reservoir_lid() {
    difference() {
        union() {
            // Outer cap body
            cylinder(d=lid_od, h=lid_h);
            // Grip flange at top
            translate([0, 0, lid_h - 3])
                cylinder(d=lid_od + 6, h=3, $fn=6);
        }
        // Bore (interior)
        translate([0, 0, -eps])
            cylinder(d=fill_d - 0.5, h=lid_skirt_h + eps);
        // Thread groove (simplified: single helical groove modelled as rings)
        // For actual threading, use a threading library or tap after print
        for (i = [0:3])
            translate([0, 0, 2 + i*lid_thread_pitch])
                difference() {
                    cylinder(d=fill_d + 1.5, h=0.8);
                    cylinder(d=fill_d - 2,   h=0.8);
                }
        // O-ring seat at cap top interior
        translate([0, 0, lid_skirt_h - 2])
            difference() {
                cylinder(d=fill_d - 0.5,    h=2.5);
                cylinder(d=fill_d - 5,      h=2.5);
            }
    }
}
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

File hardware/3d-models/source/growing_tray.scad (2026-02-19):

// ============================================================
// Growing Tray  (growing_tray.stl)
// ============================================================
// Outer: 250×250×50mm  (25×25cm = 625cm² growing area)
// Interior: 244×244×40mm
// 4× Ø8mm drain holes in 2×2 grid, 50mm from tray centre
// Retention lip (5mm high, 4mm wide) on outer base perimeter
//   slides into the growing tray ledge in the ring.
//
// Print orientation: upside-down (open face on bed).
//   Footprint: 250×250mm.  Requires 250mm bed in both axes.
//   NOTE: A 200mm bed is insufficient; 250mm minimum required.
//   Alternative: split into 2 halves at X=125mm (150mm bed OK).
//
// Material: PETG.  No supports needed.
// Post-process: none required (not a sealed water chamber).
// ============================================================

include <params.scad>

module growing_tray() {
    difference() {

        // --- Outer tray body ---
        cube([tray_w, tray_d, tray_h]);

        // --- Interior void (open top) ---
        translate([tray_wall, tray_wall, tray_floor])
            cube([tray_w - 2*tray_wall,
                  tray_d - 2*tray_wall,
                  tray_h - tray_floor + eps]);

        // --- 4× drain holes (2×2 grid in tray floor) ---
        // Holes at (125±50, 125±50) = (75,75), (75,175), (175,75), (175,175)
        cx = tray_w / 2;
        cy = tray_d / 2;
        for (dx = [-drain_inset, drain_inset])
            for (dy = [-drain_inset, drain_inset])
                translate([cx + dx, cy + dy, -eps])
                    cylinder(d=drain_d, h=tray_floor + 2*eps);

    } // end difference

    // --- Retention lip (outside of tray base perimeter) ---
    // This lip slides under the growing-tray ledge rails inside the ring,
    // holding the tray against ejection during vehicle motion.
    translate([0, 0, -tray_lip_h])
        difference() {
            cube([tray_w + 2*tray_lip_w,
                  tray_d + 2*tray_lip_w,
                  tray_lip_h]);
            translate([tray_lip_w, tray_lip_w, -eps])
                cube([tray_w, tray_d, tray_lip_h + 2*eps]);
        }
}

growing_tray();

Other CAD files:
hardware/3d-models/stl/ring_RR.stl
hardware/3d-models/stl/ring_FR.stl
hardware/3d-models/stl/sub_tray.stl
hardware/3d-models/stl/ring_RL.stl
hardware/3d-models/source/led_bracket.scad
hardware/3d-models/source/misc_parts.scad
hardware/3d-models/source/sub_tray.scad
hardware/3d-models/source/top_cap.scad
hardware/3d-models/source/tray_door.scad
hardware/3d-models/source/tray_ring.scad
hardware/3d-models/stl/led_panel.stl
hardware/3d-models/stl/ring_FL.stl

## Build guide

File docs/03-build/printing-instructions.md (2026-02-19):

# 3D Printing Instructions

**Phase:** 03 Build
**Status:** Complete
**Last Updated:** 2026-02-17

---

## Overview

All structural parts are printed in **PETG**. Pre-built STL files for all 20 parts are included in the repository at `hardware/3d-models/stl/` — ready to print or upload to a print service.

**CRITICAL: Use PETG for all parts.** PLA will warp in hot vehicles (Tg ~60°C) and degrade in moisture. PETG is mandatory for all structural, water-contact, and tray parts.

---

## Option A — Order from a 3D print service (no printer required)

If you do not have a 3D printer, any online or local print service can produce the parts:

1. **Download the STL files** from `hardware/3d-models/stl/` (20 files)
2. **Upload to a service** — for example:
   - [Craftcloud](https://craftcloud3d.com) — compares prices across many services
   - [JLCPCB 3D Printing](https://3d.jlcpcb.com) — low cost, ships internationally
   - [Treatstock](https://www.treatstock.com) — find local print shops
   - Local library or makerspace with a 3D printer
3. **Select PETG** as the material — do not accept substitution with PLA
4. **Specify quantities and infill** using the parts table below
5. **Specify 4 perimeters / wall loops** and **6 top/bottom layers** for water-tight parts (reservoir, sub-trays)

**Estimated cost from a print service:** ~$80–150 depending on service, shipping, and region (filament-only cost is ~$55; services add labour and overhead).

---

## Option B — Print yourself

Minimum build plate: 200×200mm. Heated bed required.

---

## Printer Requirements

| Requirement | Minimum | Recommended |
|---|---|---|
| Build volume | 200×200×200mm | 250×250×250mm |
| Heated bed | Yes (70°C) | Yes |
| Direct drive or Bowden | Either | Direct drive (better PETG retraction) |
| Slicer | Cura, PrusaSlicer, or Bambu Studio | PrusaSlicer 2.7+ |

---

## Global Print Settings (PETG)

| Parameter | Value | Notes |
|---|---|---|
| Layer height | 0.20 mm | Standard quality |
| First layer height | 0.25 mm | Better bed adhesion |
| Nozzle temperature | 235–245°C | Tune to your filament brand |
| Bed temperature | 70–85°C | PETG prefers warmer beds |
| Print speed | 40–60 mm/s | Slower = better layer adhesion for water-tight parts |
| Fan speed | 20–30% | PETG needs minimal cooling; too much → delamination |
| Retraction | 2–4mm (direct), 6–8mm (Bowden) | Tune to eliminate stringing |
| Perimeters / wall loops | **4** | Critical for water-tight reservoir walls |
| Top / bottom layers | **6** | Critical for water resistance |
| Infill | Per part (see table below) | |
| Infill pattern | Gyroid or grid | Gyroid for strength; grid for speed |
| Seam position | Rear | Minimises visible seam on front-facing parts |
| Supports | **None** (designed support-free) | All parts oriented for no-support FDM |
| Brim | 5mm on first layer for tall parts | Prevents warping |

---

## Parts List and Print Settings

### BASE UNIT

| Part | File | Qty | Infill | Filament | Est. Time | Notes |
|---|---|-----|---|---|---|---|
| Base front half | `base_front.stl` | 1 | 40% | 280g | 8h | Split at centre; bolt together with base_rear |
| Base rear half | `base_rear.stl` | 1 | 40% | 250g | 7h | Contains reservoir and electronics bay chambers |
| Reservoir lid | `reservoir_lid.stl` | 1 | 40% | 30g | 1h | Screw cap with O-ring groove; must be watertight |
| Waste chamber lid | `waste_lid.stl` | 1 | 40% | 20g | 0.75h | Removable for emptying |
| Electronics bay cover | `electronics_cover.stl` | 1 | 30% | 25g | 0.75h | Sealed from water zone |
| Pump mount bracket | `pump_mount.stl` | 1 | 40% | 15g | 0.5h | Holds peristaltic pump in base |

**Base subtotal: ~620g filament, ~18h**

### TRAY LEVEL RING (×3)

Each ring is split into 4 quarters for print bed compatibility. Print 3 complete sets.

| Part | File | Qty per level | Infill | Filament per set | Est. Time per set | Notes |
|---|---|---|---|---|---|---|
| Ring front-left quarter | `ring_FL.stl` | 1 | 30% | 100g | 3h | L-shaped corner quarter; front-left |
| Ring front-right quarter | `ring_FR.stl` | 1 | 30% | 100g | 3h | L-shaped corner quarter; front-right |
| Ring rear-left quarter | `ring_RL.stl` | 1 | 30% | 95g | 2.5h | L-shaped corner quarter; rear-left |
| Ring rear-right quarter | `ring_RR.stl` | 1 | 30% | 95g | 2.5h | L-shaped corner quarter; rear-right |
| **Ring subtotal (×1)** | | | | **390g** | **11h** | |
| **Ring subtotal (×3)** | | | | **1,170g** | **33h** | |

### GROWING TRAY (×3)

| Part | File | Qty | Infill | Filament | Est. Time | Notes |
|---|---|-----|---|---|---|---|
| Growing tray | `growing_tray.stl` | 3 | 30% | 60g each | 2h each | 4× Ø8mm drain holes in base; lip fits sub-tray |
| **Tray subtotal (×3)** | | | | **180g** | **6h** | |

### SUB-TRAY (×3)

| Part | File | Qty | Infill | Filament | Est. Time | Notes |
|---|---|-----|---|---|---|---|
| Sub-tray body | `sub_tray.stl` | 3 | 40% | 50g each | 1.5h each | Sealed; overflow port on side wall at 25mm; **waterproof coat required** |
| **Sub-tray subtotal (×3)** | | | | **150g** | **4.5h** | |

### LED BRACKETS (×3)

| Part | File | Qty | Infill | Filament | Est. Time | Notes |
|---|---|-----|---|---|---|---|
| LED bracket | `led_bracket.stl` | 3 | 30% | 20g each | 0.5h each | Slotted for height adjustment; holds LED panel |
| **LED bracket subtotal** | | | | **60g** | **1.5h** | |

### FRONT DOORS (×3)

| Part | File | Qty | Infill | Filament | Est. Time | Notes |
|---|---|-----|---|---|---|---|
| Hinged door | `tray_door.stl` | 3 | 20% | 30g each | 1h each | Fits ring_front hinge points; magnetic catch at closure |
| **Door subtotal** | | | | **90g** | **3h** | |

### TOP CAP

| Part | File | Qty | Infill | Filament | Est. Time | Notes |
|---|---|-----|---|---|---|---|
| Top cap body | `top_cap.stl` | 1 | 25% | 80g | 2.5h | Seed storage, bag storage, LED windows, handle |
| Seed box lid | `seed_box_lid.stl` | 1 | 25% | 15g | 0.5h | Small sliding or hinged lid for seed compartment |
| **Top cap subtotal** | | | | **95g** | **3h** | |

### MISCELLANEOUS PRINTED PARTS

| Part | File | Qty | Infill | Filament | Est. Time | Notes |
|---|---|-----|---|---|---|---|
| Tubing saddle clips | `tube_clip.stl` | 12 | 50% | 5g each | 0.25h each | Secures silicone tubing inside column every 50mm |
| Water manifold | `manifold_3way.stl` | 1 | 60% | 10g | 0.5h | 1-to-3 splitter for drip tubing; alternative to barbed fittings |
| Drip emitter cap | `drip_emitter.stl` | 3 | 60% | 3g each | 0.25h each | 2mm orifice; press-fits onto 6mm OD tubing |
| Status LED panel | `led_panel.stl` | 1 | 25% | 10g | 0.3h | 4× 3mm LED mounting panel for top cap |
| **Misc subtotal** | | | | **100g** | **4h** | |

---

## Total Filament and Time Summary

| Section | Filament | Print Time |
|---|---|---|
| Base unit | 620g | 18h |
| Tray rings (×3) | 1,170g | 33h |
| Growing trays (×3) | 180g | 6h |
| Sub-trays (×3) | 150g | 4.5h |
| LED brackets (×3) | 60g | 1.5h |
| Front doors (×3) | 90g | 3h |
| Top cap | 95g | 3h |
| Miscellaneous | 100g | 4h |
| **Total** | **~2,465g** | **~73h** |

**At $22/kg PETG: ~$54 filament cost**
**At 65+ hours print time: plan for 7–10 days on a single printer running ~10h/day**

---

## Post-Processing

### 1. Support removal
None required (all parts designed support-free).

### 2. Seam cleaning
Lightly sand any layer seams on mating surfaces with 220-grit sandpaper. Flat mating faces should be smooth for gasket sealing.

### 3. Waterproofing (CRITICAL for reservoir and sub-trays)

PETG layer lines are not inherently watertight. Apply one of the following to all interior surfaces of the **reservoir**, **waste chamber**, and **sub-trays**:

**Option A: XTC-3D Epoxy Coating (recommended)**
- Mix XTC-3D 2:1 by volume
- Apply thin coat with a foam brush to all interior surfaces
- Let cure 4 hours; apply second coat if needed
- Fully cured in 24 hours
- Result: glassy, hard, fully watertight
- Cost: ~$15–20 per bottle (covers 3–4 parts)

**Option B: Rustoleum Crystal Clear spray lacquer**
- Apply 3–4 coats to interior, letting each dry 30 min
- Not as robust as XTC-3D but adequate for water-at-rest (not pressure)
- Cost: ~$8–12

**Option C: Silicone RTV**
- Brush RTV silicone into all joints and seams only (not full surface coat)
- Requires 24h cure before water contact
- Good for joints; combine with Option A or B for full waterproofing

**Test before first use:** Fill the reservoir and sub-trays with water and leave for 24 hours. Check for weeping. Re-coat if needed.

### 4. Assembly of split parts

Base front + rear halves join with:
- 6× M3×20mm bolts and M3 nuts through pre-printed holes
- PETG solvent weld (dichloromethane or MEK applied to seam with cotton swab; allow 10 min to bond) — optional for watertight seam
- Bead of RTV silicone on inner seam surface before bolting together

### 5. Heat-set inserts

Vehicle mounting points (4× M5 in base corners): use a soldering iron at 200°C to press-fit M5 threaded heat-set inserts into the pre-printed recesses.

### 6. Light-sealing

Apply 3mm closed-cell foam weather-strip to all ring section interfaces (top and bottom flanges) and around door perimeters. This prevents light leakage between levels, which would disrupt the blackout phase of adjacent trays.

---

## Print Order Recommendation

Print in this order to allow waterproofing and testing before completing the full enclosure:

1. **Reservoir + waste chamber** (base halves) → waterproof → fill test
2. **One tray ring** (4 quarter-parts) → assemble → fit test
3. **One growing tray + one sub-tray** → waterproof sub-tray → water test
4. **LED bracket** → test with LED panel
5. **Front door** → fit to ring
6. If prototype test passes: print remaining 2 rings, 2 growing trays, 2 sub-trays
7. **Top cap** last (after full electrical assembly is confirmed)

---

## Print Troubleshooting

| Problem | Cause | Solution |
|---|---|---|
| PETG stringing | Too-high temp or too-low retraction | Reduce temp 5°C; increase retraction 0.5mm increments |
| Part warping | Bed too cold or draft | Increase bed temp to 85°C; enclose printer |
| Layer delamination | Fan speed too high | Reduce fan to 20% or off for first 10 layers |
| Leaking reservoir | Insufficient perimeters | Reprint with 5 walls; apply XTC-3D coat |
| Tray doesn't slide smoothly | Dimensional tolerance | Sand the slide rails lightly; PETG is slightly flexible and will break in |
| Door hinge too tight | FDM tolerance | Drill out hinge hole slightly with 3mm drill bit |

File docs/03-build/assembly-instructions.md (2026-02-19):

# Assembly Instructions

**Phase:** 03 Build
**Status:** Complete
**Last Updated:** 2026-02-18

---

## About This Guide

This guide explains how to build the Microgreen Box from scratch. No previous electronics or growing experience is required. Every technical term is explained the first time it appears. Read each step fully before doing it.

**What you will build:** A self-contained growing device that automatically grows broccoli microgreens. It controls its own lights and watering schedule. You press a button once to start a grow, and a buzzer and LED tell you when the harvest is ready.

**Before starting this guide, confirm you have:**
- All electrical components (ordered per `bom/bill-of-materials.csv`)
- All consumables (seeds, coir pucks — ordered per `docs/03-build/parts-list-consumables.md`)
- All 3D-printed parts (see Section A below)
- All tools listed in Section B

**Estimated assembly time:** 6–8 hours, split across 3 days to allow waterproofing to cure.

> **Renders:** See `hardware/3d-models/renders/` for visual diagrams of each assembly stage.

---

## Section A: Getting the 3D-Printed Parts

The enclosure, trays, and brackets are all 3D-printed in PETG plastic. You can either print them yourself or order them from an online print service.

### What is PETG?

PETG (polyethylene terephthalate glycol) is a food-safe, moisture-resistant plastic commonly used for 3D printing. It is much more durable and heat-tolerant than PLA (the most common home 3D printing material). **All parts in this device must be printed in PETG — never PLA.** PLA softens in a warm vehicle and absorbs moisture over time, causing parts to warp.

### Option 1: Order from an Online Print Service

If you do not have a 3D printer, or you want higher quality parts, use an online service. Upload the STL files and they will print and ship the parts to you.

**Recommended services:**
- **Craftcloud** (craftcloud3d.com) — compares prices across many printers worldwide
- **Treatstock** (treatstock.com) — finds local print services near you
- **JLCPCB 3D Print** (jlcpcb.com) — very low cost; ships worldwide; 2–4 week delivery
- **PCBWay** (pcbway.com) — good quality; ships worldwide
- Local makerspaces — search "[your city] makerspace 3D printing"

**What to tell the service:**

| Setting | Value | Why |
|---|---|-----|
| Material | **PETG** | Required — water resistant, food safe, vehicle safe |
| Layer height | 0.2 mm | Balance of quality and print time |
| Wall count / perimeters | **4 walls** | Structural strength and water tightness |
| Top/bottom layers | **6 layers** | Minimises porosity on water-contact surfaces |
| Infill | **40%** for structural parts; **80%** for sub-trays and reservoir body | Higher infill = less water seepage |
| Supports | **None required** | All parts designed support-free |

**STL files:** Generate from source by running `make all` in `hardware/3d-models/`. Requires OpenSCAD 2021.01 or later (`sudo apt install openscad`).

**Parts to order:**

| File | Qty | Notes |
|---|-----|---|
| `base_front.stl` | 1 | Base unit — front half |
| `base_rear.stl` | 1 | Base unit — rear half (reservoir + waste chamber) |
| `reservoir_lid.stl` | 1 | Reservoir lid (float switch gland pre-formed) |
| `waste_lid.stl` | 1 | Waste chamber snap-fit lid |
| `electronics_cover.stl` | 1 | Electronics bay cover |
| `pump_mount.stl` | 1 | Pump bracket |
| `ring_FL.stl` | 3 | Tray ring front-left quarter (×3 rings = 3 parts) |
| `ring_FR.stl` | 3 | Tray ring front-right quarter |
| `ring_RL.stl` | 3 | Tray ring rear-left quarter |
| `ring_RR.stl` | 3 | Tray ring rear-right quarter |
| `growing_tray.stl` | 3 | Growing tray (holds coir and seeds) |
| `sub_tray.stl` | 3 | Sub-tray (sealed water-retention tray, high infill) |
| `led_bracket.stl` | 3 | Adjustable LED grow strip holder |
| `tray_door.stl` | 3 | Front access door per tray level |
| `top_cap.stl` | 1 | Top cap with seed storage and handle |
| `seed_box_lid.stl` | 1 | Lid for seed storage compartment |
| `led_panel.stl` | 1 | Status LED panel insert |
| `manifold_3way.stl` | 1 | Water tube 1-to-3 splitter |
| `drip_emitter.stl` | 3 | Drip nozzle, one per tray (2 mm orifice) |
| `tube_clip.stl` | 12 | Tubing saddle clips |

**Approximate total material:** ~2.4 kg PETG
**Estimated cost from a print service:** $80–200 USD depending on service and delivery region.

### Option 2: Print Yourself

If you have a printer with at least a 200×200 mm print bed, all parts fit. The growing tray and sub-tray are larger (250×256 mm) and may need to be split further for smaller beds — see `docs/03-build/printing-instructions.md` for settings, part order, and bed-size handling. Total print time: approximately 65 hours.

---

## Section B: Tools and Hardware

**Tools required:**

| Tool | Purpose |
|---|---|
| Screwdriver — Phillips #2 | Standard M3 screws |
| Screwdriver — small flat-blade | Relay screw terminals; buck converter adjustment screw |
| 2 mm hex key | M3 socket-head bolts |
| Pliers | Holding nuts; pressing magnets |
| Wire strippers | Stripping insulation from wire ends |
| Wire cutters | Cutting wire and silicone tubing |
| Soldering iron + solder | Attaching wires to components |
| Multimeter | Checking voltage and continuity before power-on |
| Helping hands (optional) | Holding small parts while soldering |
| Silicone applicator or old toothbrush | Spreading RTV sealant |
| 3 mm drill bit + hand drill | Clearing hinge holes if tight |
| Scissors | Cutting foam weatherstrip |
| Measuring tape or ruler | Setting LED height above tray |

**Additional hardware (not included in BOM):**

| Item | Qty | Purpose |
|---|-----|---|
| M3×20 mm button-head bolt | 36 | Joining rings and base flanges (6 per joint × 6 joints) |
| M3×10 mm bolt | 20 | LED brackets, misc |
| M3×6 mm bolt | 12 | LED panel attachment |
| M3 hex nut | 40 | Captured nut sockets in flanges |
| M3×30 mm bolt | 9 | Door hinge pins (3 per door × 3 doors) |
| M5 heat-set insert | 4 | Vehicle mounting corners in base |
| 3 mm closed-cell foam weatherstrip | 2 m | Light-sealing ring flanges |
| 4×2 mm foam weatherstrip | 1 m | Door perimeter light seals |
| RTV silicone sealant | 1 tube | Waterproofing seams; ring assembly |
| O-ring, Ø40 mm × 2 mm cross-section | 1 | Reservoir lid water seal |
| Ø8×3.5 mm neodymium disc magnets | 6 | Door catches (2 per door) |
| CA glue (super glue) | 1 small bottle | Bonding door catch magnets |
| CR2032 coin cell battery | 1 | RTC (clock) module time backup |

---

## Section C: Waterproofing — Do This First (2 Days Before Assembly)

Some 3D-printed parts hold water inside the device. Even high-infill PETG can seep slowly through the layer seams. Parts that contain water must be coated inside with a waterproofing sealant before assembly.

### Which parts need waterproofing?

- **Inside the reservoir cavity** (the large chamber in `base_rear.stl`)
- **Inside the waste chamber** (the smaller chamber in `base_rear.stl`)
- **All three `sub_tray.stl` parts** (the sealed water-retention trays that sit below each growing tray)

### Which parts do NOT need waterproofing?

Growing trays (water drains through them intentionally), tray rings, doors, top cap, electronics bay, LED brackets.

### What you need for waterproofing

**XTC-3D epoxy coating** (by Smooth-On) is the recommended sealant. It is a two-part liquid epoxy that you mix and paint onto the inside of a print. It flows into the layer seams, seals the surface, and cures to a hard, food-safe coating. Available from Smooth-On distributors, Amazon, or 3D printing supply shops. **Alternatively:** Rust-Oleum Crystal Clear Enamel spray works on less critical surfaces.

- Mixing cups (small disposable cups)
- Disposable brushes (foam brushes work well)
- Nitrile gloves
- Well-ventilated area (the uncured epoxy fumes are unpleasant)

### Waterproofing procedure

**Step W1.** Put on gloves. Mix XTC-3D Part A and Part B at a **2:1 ratio by volume** (the label has measurements). Stir continuously for 60 seconds. You have about 10 minutes to apply before the mixture becomes too thick to brush.

**Step W2.** Using a brush, paint a thin, even coat over all interior surfaces of the reservoir cavity, waste chamber, and the interiors of all three sub-trays. The coat should be thin — XTC-3D self-levels. Thick coats form runs and drips.

**Step W3.** Leave each part horizontal. Do not move for at least 4 hours. The resin cures to handling strength in 4 hours and fully in 24 hours.

**Step W4.** After full cure (24 hours), apply a **second coat** exactly as above. Two thin coats are better than one thick coat.

**Step W5 — Water test:** After the second coat cures (another 24 hours), place each coated part on dry paper towels and fill with water. Leave for 24 hours. Check the paper towels — if completely dry, the seal is good. If damp anywhere, dry for 24 hours, apply a third coat to that area, cure again, and re-test before proceeding.

> **Common mistake:** Skipping the water test. A slow seep that is invisible after 1 hour becomes a visible drip after 12 hours. Always water-test before assembling electronics nearby.

---

## Step-by-Step Assembly

Steps are numbered sequentially throughout the guide.

---

### Step 1 — Set the Buck Converter to 5.0 V

**What is a buck converter?** A buck converter (also called a step-down converter) is a small circuit board that converts a higher voltage to a lower voltage. In this device it converts the 12 V power input down to 5 V, which the ESP32 microcontroller requires.

**What is an ESP32?** The ESP32 is the small computer that controls the entire device. It runs the firmware (the software that manages lights, watering, alarms, and schedules). It connects to everything via its GPIO (General Purpose Input/Output) pins — the rows of metal pins along its sides.

> **Critical warning:** If the voltage is higher than 5.1 V when you connect the ESP32, you may permanently damage it. Set the voltage before connecting anything to the output.

1. Identify the **buck converter** — a small green or blue circuit board approximately 22×17 mm, with a small brass adjustment screw on top and four pads or screw terminals (IN+, IN−, OUT+, OUT−).

2. Connect a 12 V power supply temporarily to the **input** of the buck converter only:
   - Red wire to IN+ (positive input)
   - Black wire to IN− (ground input)
   - Do not connect anything to the output yet.

3. Set your multimeter to **DC Voltage, 20 V range**. Touch the red probe to OUT+ and the black probe to OUT−.

4. While watching the multimeter reading, turn the small brass adjustment screw:
   - Clockwise = voltage increases
   - Counter-clockwise = voltage decreases
   - Adjust until the reading is exactly **5.0 V** (±0.05 V is acceptable).

5. Disconnect the 12 V supply. The buck converter is now set and ready to install.

---

### Step 2 — Remove the Relay Module JD-VCC Jumper

**What is a relay?** A relay is an electrically controlled switch. The ESP32 operates at 3.3 V with very little current — not enough to power grow lights or a pump directly. A relay uses a small electromagnetic coil to switch a much higher-power circuit on and off. When the ESP32 sends a signal to the relay, the coil pulls a metal contact arm, completing the power circuit to the load (LED strip or pump).

**What is the JD-VCC jumper and why remove it?** The relay module has two separate power rails on board:
- The **logic side** (receives control signals from the ESP32) — powered at 3.3 V
- The **coil side** (powers the electromagnetic coils that actually switch) — powered at 5 V

A small plastic jumper cap bridges these two rails together by default. With this jumper in place, the relay coils draw their power from the same rail as the ESP32. When multiple relays fire at once, the coil current (70–100 mA per relay) can cause the ESP32's voltage to dip, causing it to reset or malfunction.

> **Critical step:** Remove this jumper before installing the relay module. Once removed, the two sides are isolated by the opto-couplers on the board (opto-couplers are optical isolators that pass signals as light beams, preventing electrical interference between sides).

1. Locate the relay module — a blue board with 4 large black relay boxes and a row of 6 input pins on one side (labelled VCC, GND, IN1, IN2, IN3, IN4) and a separate pair of pins nearby labelled **JD-VCC** and **VCC**.

2. Find the **jumper cap** — a small plastic rectangle bridging the two adjacent pins labelled JD-VCC and VCC. It may be blue, yellow, or black.

3. Grip the jumper cap with your fingernails or pliers and **pull it straight off**. Keep it in case you need to identify it later, or discard it.

4. Confirm the two pins are now bare (no cap connecting them). This is correct.

> **Common mistake:** Forgetting this step. The device will appear to work but will randomly reset when multiple relays activate. Always remove the jumper first.

---

### Step 3 — Join the Base Unit Halves

**What is the base unit?** The base is the bottom section of the device. It contains the water reservoir (the tank that stores water for watering), the waste chamber (a sealed compartment that collects any overflow water), and the electronics bay (a dry compartment for the circuit boards).

**Parts:** `base_front.stl`, `base_rear.stl`
**Hardware:** 6× M3×20 mm bolts, 6× M3 hex nuts, RTV silicone sealant, soldering iron, 4× M5 heat-set inserts

1. Lay both halves on a flat surface with the flat split faces facing up.

2. Examine the **rear half**: you will see the large reservoir cavity and smaller waste chamber cavity — both already waterproofed and water-tested in Section C.

3. Apply a continuous bead of **RTV silicone** along the flat split face of the rear half, specifically along the entire edge of the reservoir and waste chamber cavities where they cross the split line. Use the applicator to press the bead into the joint face.

4. Press the two halves together, aligning all bolt holes.

5. Insert **6× M3 hex nuts** into the rectangular nut pockets on the rear half (visible along the joint face).

6. Thread **6× M3×20 mm bolts** through the front half and into the hex nuts in the rear half. Tighten firmly — snug, but do not strip the plastic.

7. Wipe away excess RTV from the exterior with a damp cloth.

8. **Wait at least 2 hours** before moving the base. RTV silicone needs 24 hours to fully cure — do not fill with water for 24 hours.

#### Sub-step: Install vehicle mounting inserts

9. Locate the four recessed circular pockets on the underside of the base (one at each corner). These accept M5 heat-set inserts for bolting the device to a vehicle surface.

10. Heat your **soldering iron to approximately 200°C** (a medium setting). Place one **M5 heat-set insert** (a small brass threaded cylinder) flat on top of a pocket. Press the soldering iron tip gently onto the insert. The surrounding plastic will melt and the insert will sink in. Stop when the insert top sits flush with the surface.

11. Remove the iron. Wait 1 minute for the plastic to re-solidify before moving to the next corner. Repeat for all 4 corners.

---

### Step 4 — Install the Float Switch in the Reservoir Lid

**What is a float switch?** A float switch is a water level sensor. The ZP2508 is a small cylinder about 25 mm long containing a magnetic reed switch and a small ball that floats on water. When the water level drops, the ball drops with it, which causes the switch contacts to change state, signalling the device that the reservoir needs refilling.

**What does NC mean?** NC stands for Normally Closed. A normally-closed switch has its two contacts touching (allowing electricity to flow) when the switch is in its natural resting position — in this case, when the float ball is at the bottom (low water). When water rises and lifts the float, the contacts separate (open), stopping the flow of electricity. This means: **low water = contacts closed = ESP32 reads LOW = alarm triggered.**

**Component:** ZP2508 NC float switch
**Part:** `reservoir_lid.stl`
**Hardware:** O-ring Ø40 mm × 2 mm, cable gland nut (part of ZP2508)

1. Thread the **float switch body** down through the 6 mm gland hole in the reservoir lid from the top. A gland is a fitting that allows a component to pass through a wall and seals around it to prevent leaks.

2. Tighten the **gland nut** from below the lid until it is snug — the rubber inside the gland compresses around the switch body and creates a water-tight seal.

3. The float ball should hang freely below the lid, pointing downward into the reservoir when the lid is fitted.

4. Seat the **O-ring** into the groove on the underside of the reservoir lid.

5. Thread the **reservoir lid** onto the fill-port boss (the threaded collar on the top of the base rear) until snug. The O-ring compresses and seals the lid to the base.

6. Route the **two float switch wires** through the cable pass-through slot in the base down into the electronics bay. You will connect them to the ESP32 in Step 9.

---

### Step 5 — Build the Electronics Board

**What is a stripboard?** A stripboard (also called Veroboard) is a small circuit board with rows of copper tracks printed on it. You solder components to it to build circuits. Where you need to break the copper track (to prevent connections you do not want), you use a small drill or tool to cut through the track.

**Components:** Buck converter (MP1584EN), inline 5 A fuse holder + 5 A fuse, reverse polarity protection (AO3401 P-channel MOSFET, or simpler: 1N5400 diode), 5.5/2.1 mm DC barrel jack

1. Mount the **stripboard** in the electronics bay using M3×8 mm standoff bolts or double-sided foam tape. The electronics bay is the compartment in the front-left section of the base.

2. **Reverse polarity protection:** If someone connects the 12 V supply backwards, this component prevents damage to the electronics.
   - If using the **1N5400 diode** (recommended for beginners): solder it in series on the +12 V input line with the stripe (cathode, the end marked with a line or band) pointing toward the rest of the circuit. Current flows in the correct direction; if reversed, the diode blocks it.
   - If using the **AO3401 MOSFET**: see `hardware/schematics/wiring-schematic.md` for pin orientation.

3. Solder the **5 A inline fuse holder** in series on the +12 V line, downstream of the polarity protection component. Insert a 5 A blade fuse into the holder.

4. Solder the **buck converter** input pads to the 12 V bus: red (positive) to the + track, black (negative/ground) to the − track. The buck converter output (5.0 V, set in Step 1) will power the ESP32 and relay coils.

5. Install the **DC barrel jack** in the pre-printed hole on the left outer wall of the base. Thread the panel-mount nut onto the exterior of the jack and tighten with pliers. Solder 20 AWG (the thicker) red and black leads from the jack to the stripboard input.

> **Polarity on barrel jacks:** The centre pin of a standard 5.5/2.1 mm barrel jack is **positive (+12 V)**. The outer sleeve is negative (ground). Verify with your multimeter before connecting anything downstream.

---

### Step 6 — Mount the ESP32 and RTC Module

**What is the RTC module?** RTC stands for Real-Time Clock. The DS3231 module is a dedicated clock chip that keeps the current time even when the main power is off, using a small CR2032 coin cell battery (the same type used in watches and key fobs). The device uses this clock to turn lights on at 06:00 and off at 20:00, and to run the watering schedule at 07:00 and 19:00 each day.

**What is I2C?** I2C (pronounced "I-squared-C") is a communication protocol that lets multiple devices share just two wires — SDA (data) and SCL (clock). Both the RTC module and the optional OLED display use I2C, connected to the same two ESP32 pins.

**Components:** ESP32-WROOM-32 dev board, DS3231 RTC module, CR2032 coin cell

1. Press a **CR2032 coin cell** into the holder on the DS3231 RTC module. The flat positive (+) side faces up.

2. Mount the **ESP32 dev board** on the stripboard using the provided male pin headers (the rows of metal pins). The ESP32 should sit elevated above the stripboard on the pin headers, with all pins accessible.

3. Connect the **DS3231 RTC module** to the ESP32 using 24 AWG (thinner signal) wire:

   | DS3231 pin | Connects to | Note |
   |-----------|-------------|------|
   | VCC | ESP32 3.3V pin | 3.3V only — not 5V |
   | GND | GND | Common ground |
   | SDA | ESP32 GPIO 21 | I2C data line |
   | SCL | ESP32 GPIO 22 | I2C clock line |

4. Leave enough wire slack to comfortably close the electronics cover later. Tuck wires along the bay walls.

---

### Step 7 — Mount and Wire the Relay Module

**Components:** 4-channel relay module (jumper already removed in Step 2)

1. Mount the **relay module** in the front-right area of the base using M3×8 mm bolts through its mounting holes.

2. Connect **power** to the relay module:

   | Relay module pin | Wire to | Why |
   |-----------------|---------|-----|
   | VCC | ESP32 3.3V | Logic power — signals only |
   | GND | GND (common ground) | Shared ground |
   | JD-VCC | 5V from buck converter output | Coil power — isolated from logic |

   > These must be two separate connections. VCC goes to 3.3V; JD-VCC goes to 5V. Do not connect both to the same voltage. This is what the removed jumper was doing — you are now making this connection explicitly with separate wires.

3. Connect the **control inputs** (IN1–IN4) to the ESP32 GPIO pins:

   | Relay pin | ESP32 GPIO | What it controls |
   |----------|-----------|-----------------|
   | IN1 | GPIO 26 | LED grow strip — Tray A (bottom ring) |
   | IN2 | GPIO 27 | LED grow strip — Tray B (middle ring) |
   | IN3 | **GPIO 25** | LED grow strip — Tray C (top ring) |
   | IN4 | **GPIO 13** | Peristaltic pump |

   > **Important:** GPIO 25 (not GPIO 14) controls Tray C. GPIO 13 (not GPIO 12) controls the pump. GPIOs 14 and 12 are reserved for the ESP32's internal boot process and must not be used for relay control.

4. Wire the **relay output contacts** (the high-power switching side). For each channel, use 20 AWG red and black wire:
   - +12 V bus → relay **COM** (common) contact of that channel
   - Relay **NO** (Normally Open) contact → positive (+) wire of the LED strip or pump
   - Negative (−) wire of the LED strip or pump → GND directly

   > **What is NO?** Normally Open means the contact is open (no connection) when the relay is off. When the relay activates, the contact closes and allows current to flow. This means loads are OFF when the ESP32 is not signalling — correct and safe behaviour.

   > **Active-LOW:** This relay module activates when the control pin is pulled LOW (0V by the ESP32). ESP32 pin LOW → relay ON → load switches ON. The firmware is written to match this.

---

### Step 8 — Install Status Indicators

**Components:** 4× 3 mm LEDs (1 green, 1 yellow, 2 red), 4× 330Ω resistors (orange-orange-brown stripes), optional active buzzer, 1× 100Ω resistor (brown-black-brown stripes)

**What is a current-limiting resistor?** LEDs burn out if too much current flows through them. A resistor limits the current to a safe amount. The 330Ω resistors used here limit current to about 10 mA from a 3.3V GPIO pin — bright enough to see clearly without damaging the LED.

1. For each LED, solder a **330Ω resistor** to the longer leg (the positive leg, called the anode). Cover the solder joint with a small piece of heat-shrink tubing and shrink it with the soldering iron. The shorter leg (cathode, negative) connects to GND.

2. Connect each LED to the ESP32:

   | LED colour | ESP32 GPIO | Meaning when lit |
   |-----------|-----------|-----------------|
   | Green | GPIO 18 | System OK (blinks slowly as heartbeat) |
   | Yellow | GPIO 19 | Reservoir water level is low — refill needed |
   | Red (first) | GPIO 5 | Tray A is ready to harvest |
   | Red (second) | GPIO 17 | Tray B or Tray C is ready to harvest |

3. Run the LED wires up through the ring cable channels. They will connect to the status LED panel in the top cap in Step 15.

4. **Buzzer (optional):** Connect the positive pin of the active buzzer to ESP32 GPIO 16 through a 100Ω resistor. Connect the negative pin to GND. An active buzzer contains its own oscillator — it makes a tone when powered and needs no extra signal.

---

### Step 9 — Wire the Float Switch

1. Locate the two wires from the **ZP2508 float switch** routed into the electronics bay in Step 4. The wires are identical — either can connect to either terminal.

2. Connect one wire to **ESP32 GPIO 33**.

3. Connect the other wire to **GND**.

4. The firmware configures GPIO 33 as INPUT_PULLUP (the ESP32 internally connects a weak resistor pulling this pin to 3.3V):
   - **Normal (water present):** Float ball lifted → NC contacts open → GPIO 33 = 3.3V (HIGH) → no alarm
   - **Water low:** Float ball drops → NC contacts close → GPIO 33 connected to GND → LOW → alarm triggers

> **Fail-safe behaviour:** If the float switch wire breaks or disconnects, GPIO 33 is no longer pulled to GND, so it reads HIGH — no false alarm. The alarm only activates when water is genuinely low.

---

### Step 10 — Install Moisture Sensors

**What is a capacitive moisture sensor?** Each growing tray has a sensor that measures how moist the coir is. It works by detecting the electrical capacitance of the material around its probe — wet coir has a different capacitance than dry coir. The sensor outputs a voltage that the ESP32 converts to a moisture percentage.

**Why capacitive, not resistive?** Older resistive moisture sensors pass a small current through the growing medium, which causes the sensor to corrode over months. Capacitive sensors have no exposed metal contacts in the growing medium and last much longer.

**Components:** 3× Capacitive Soil Moisture Sensor V1.2 (a small circuit board with a long flat probe, approximately 90×20 mm)

1. Connect each sensor to the ESP32 using 24 AWG wire:

   | Sensor | Sensor pin | ESP32 / board connection |
   |--------|-----------|--------------------------|
   | Tray A sensor | VCC | 3.3V (not 5V) |
   | Tray A sensor | GND | GND |
   | Tray A sensor | AOUT | **GPIO 34** |
   | Tray B sensor | VCC | 3.3V |
   | Tray B sensor | GND | GND |
   | Tray B sensor | AOUT | **GPIO 35** |
   | Tray C sensor | VCC | 3.3V |
   | Tray C sensor | GND | GND |
   | Tray C sensor | AOUT | **GPIO 32** |

   > **Note on GPIO 34 and 35:** These are input-only pins on the ESP32. They can only read voltages — they cannot output signals or drive LEDs. This is ideal for sensors.

   > **Use 3.3V, not 5V:** These sensors work at 3.3V. Connecting to 5V may damage them.

2. Route each sensor cable up through the ring cable channels to the corresponding tray level. Leave 15 cm of slack at the tray end so the sensor can be positioned in the coir.

3. The sensors will be inserted into the coir when trays are seeded. For now, clip the sensor cables along the ring walls with `tube_clip.stl` and leave the probe ends coiled and stored.

> **Calibration required:** After assembly and before trusting the moisture readings, calibrate the sensors per `docs/04-software/installation-guide.md` Step 10. The default values are approximate.

---

### Step 11 — Mount the Pump and Route Tubing

**What is a peristaltic pump?** A peristaltic pump moves liquid by squeezing a flexible tube with rollers. The liquid never touches the pump mechanism — only the inside of the tube. This design means the pump works in any orientation (including tilted in a vehicle), can be run dry without damage, and can pump food-grade liquids safely.

**Parts:** `pump_mount.stl`, `manifold_3way.stl`, 3× `drip_emitter.stl`, 12× `tube_clip.stl`
**Component:** 12V DC peristaltic pump, silicone tubing

1. Bolt the **peristaltic pump** to the `pump_mount.stl` bracket using the pump's built-in M3 mounting holes.

2. Bolt the **pump bracket** to the floor of the front-right area of the base using 4× M3×10 mm bolts.

3. Connect the **pump power leads** to relay module Channel 4 load contacts:
   - Pump + lead (red) → relay CH4 NO contact
   - Pump − lead (black) → GND

4. Cut a piece of silicone tubing (~150 mm long) and push one end onto the **reservoir outlet barb** on the base (a small tube fitting near the reservoir base). Push the other end onto the **pump inlet**.

5. Push the **3-way manifold** (`manifold_3way.stl`) onto the pump outlet barb with a short piece of tubing.

6. Cut three supply tube runs — long enough to reach from the manifold to each tray level. Route each tube:
   - Up through the Ø7 mm hole in the base top face
   - Up through the ring interior along the rear wall
   - To the drip port hole at the rear of the corresponding tray level

7. Secure the tubing every 50 mm with `tube_clip.stl` saddle clips fixed with 2.5 mm self-tap screws.

8. Push a **drip emitter** (`drip_emitter.stl`) onto the end of each supply tube at the tray-level drip port. The 2 mm orifice in the emitter limits flow to approximately 25 mL per pump event per tray.

9. **Waste drain tubing:** Cut three waste tube runs and connect from each sub-tray's rear drain fitting down through the ring interiors to the waste chamber inlet port on the base top. Secure with clips as above.

> **Tubing tip:** Silicone tubing is stiff when cold. Briefly dipping the end in boiling water for 5 seconds softens it and makes it much easier to push onto barbs.

---

### Step 12 — Assemble and Stack Tray Rings

Each tray level is a ring built from four L-shaped quarter-section pieces. This section assembles all three rings and stacks them.

**Parts (per ring):** `ring_FL.stl`, `ring_FR.stl`, `ring_RL.stl`, `ring_RR.stl`
**Hardware (per ring):** RTV silicone, 8× M3×20 mm bolts, 3 mm foam weatherstrip

#### Assemble each of the three rings (repeat × 3):

1. Lay the four quarter-sections (FL=front-left, FR=front-right, RL=rear-left, RR=rear-right) on a flat surface arranged in their correct positions, flanges facing down.

2. Apply a thin bead of **RTV silicone** along each of the four vertical seam faces where the quarters join.

3. Push the four quarters together. Thread **2× M3×20 mm bolts** through each seam boss (there are 4 seam locations, 2 bolts each = 8 bolts per ring). Tighten uniformly.

4. Apply **3 mm closed-cell foam weatherstrip** to the inner face of both the top flange and bottom flange of the assembled ring. This foam compresses between levels when stacked, creating a light seal that prevents light from one ring leaking into the ring below and disrupting the germination blackout period.

   > **Passive ventilation slots and insect screens:** Each assembled ring has two **25×8mm vent slots** near the top of the front and rear walls, each fitted with a removable slide cover. Before stacking the rings, fit an insect screen patch over each slot opening:
   >
   > **Vent slot insect screen installation (do this before stacking):**
   > 1. Cut 6 patches of fiberglass insect screen mesh (E34) to **27×10mm** each (slightly wider and taller than the slot so the edges are captured).
   > 2. Apply a thin bead of **RTV silicone** around the perimeter of each vent slot opening on the **interior** wall face.
   > 3. Press one mesh patch over each slot opening and hold flat for 60 seconds. The mesh overlaps the slot edges by ~1mm all round.
   > 4. Allow RTV to cure for 30 minutes before stacking. The screen is now permanent — it stays in place whether the slide cover is in or out.
   >
   > **Operation:** Leave slide covers in place for normal operation — they maintain the light seal. Remove slide covers on one or more rings when ventilation is needed; the mesh provides continuous insect protection even with covers removed. The mesh pore size (~1.2mm) blocks fungus gnats, shore flies, and other common microgreen pests while allowing full airflow.

5. Wait 30 minutes for RTV to set before stacking.

6. Check the interior: you should see two pairs of horizontal ledge rails on the inner walls:
   - **Lower ledge rails** at 20 mm from the ring floor — these support the sub-tray
   - **Upper ledge rails** at 64 mm from the ring floor — these support the growing tray

#### Stack the rings:

7. Place **ring 1** (Tray A, bottom) on the base top face. Align the 6× bolt holes in the ring bottom flange with the holes in the base top face.

8. Thread **6× M3×20 mm bolts** through the ring flange holes into captured hex nuts in the base top face. Tighten uniformly.

9. Stack **ring 2** (Tray B, middle) on top of ring 1. Use 6× M3×20 mm bolts through the ring flange joint.

10. Stack **ring 3** (Tray C, top) on ring 2. Use 6× M3×20 mm bolts.

11. After each joint, confirm the foam weatherstrip is compressed slightly between flanges — if the foam is not compressing, the rings may not be fully seated. Press down firmly while tightening.

---

### Step 13 — Install Sub-Trays and Growing Trays

**What is the sub-tray?** The sub-tray is a sealed water-retention tray that sits below the growing tray in each ring level. Water drains through the growing tray's drain holes into the sub-tray, keeping the coir moist from below. An overflow port on the sub-tray rear wall connects to the waste drain tube, preventing overflow.

**What is the growing tray?** The growing tray holds the coir and seeds. Four 8 mm drain holes in its base allow water to drip through into the sub-tray below. The growing tray sits elevated above the sub-tray on ledge rails, allowing airflow underneath.

**Parts:** `sub_tray.stl` (×3), `growing_tray.stl` (×3)

> Pre-requisite: Sub-trays must have been waterproofed and water-tested per Section C.

1. Slide each **sub-tray** into its ring level from the front door aperture, onto the lower ledge rails (20 mm from floor). It slides horizontally like a drawer.

2. Connect the **waste drain tube** to the rear drain fitting of each sub-tray (push-fit Ø8.5 mm barb). Route the tube as established in Step 11.

3. Slide each **growing tray** into its ring level onto the upper ledge rails (64 mm from floor). The growing tray sits above and separated from the sub-tray.

4. Verify that the growing tray's 4× drain holes sit above the interior of the sub-tray below — not above the ledge rails. Water must drip into the sub-tray interior.

> The moisture sensors will be inserted into the coir when you seed each tray for the first time. Leave the sensor probes coiled in each ring level for now.

---

### Step 14 — Install LED Grow Strips

**What is a full-spectrum grow strip?** A grow strip is an LED strip light with the correct wavelengths for plant growth — it includes blue, red, and green wavelengths similar to sunlight. "Full spectrum" means it mimics natural daylight, which is more effective for plant growth than a single-colour light.

**Parts:** `led_bracket.stl` (×3)
**Components:** 3× sections of 12 V full-spectrum LED grow strip, each cut to 250 mm

1. Mount one **LED bracket** on the rear inner wall mounting rail of each ring using 2× M3×10 mm bolts through the bracket's slotted holes (the slot allows height adjustment).

2. Set each bracket height so the **LED strip will be approximately 100 mm above the growing tray surface** when installed. Measure from the tray surface (with the growing tray in place) up to where the LED strip will sit.

3. Cut the LED grow strip into three **250 mm sections** at the cut marks printed on the strip (usually every 25–50 mm between LEDs). Use scissors or a sharp knife. Always cut exactly on the marked cut line — cutting through an LED ruins that section.

   > **Polarity:** LED strips only light up in one direction. Look for a + and − marking near the cut end. The + wire connects to the relay NO contact; the − wire connects to GND.

4. Press each **LED strip** into the bracket channel and secure with 2× M3×6 mm bolts.

5. Connect LED leads via the JST-XH 2-pin connector (or solder if connectors are not supplied):
   - Tray A strip (bottom ring) + → relay CH1 NO contact
   - Tray A strip − → GND
   - Tray B strip (middle ring) + → relay CH2 NO contact
   - Tray C strip (top ring) + → relay CH3 NO contact

6. Route LED wires through the wire pass-through slot at the front of each ring wall, running down to the relay module.

---

### Step 15 — Install Front Doors

**Parts:** `tray_door.stl` (×3), 6× Ø8×3.5 mm neodymium disc magnets, CA glue

1. Press **4×2 mm foam weatherstrip** into the groove running around the perimeter of the inside of each door. The foam should sit proud of the door face by about 1 mm — it will compress when the door is shut.

2. **Hang each door** by aligning the door's hinge knuckles (the semi-circular loops along the door's left edge) with the matching knuckles on the ring aperture.

3. Insert **hinge pins:** push an M3×30 mm bolt down through all the stacked knuckles (door and ring alternated). Thread an M3 nut on the bottom and tighten to retain the pin.

4. Test the door: it should swing open approximately 90° without binding. If it binds, enlarge the hinge hole slightly with a 3 mm drill bit and try again.

5. **Install door catch magnets:**
   - Press one magnet into the pocket on the ring aperture edge
   - Press the second magnet into the matching pocket on the door edge
   - Before gluing, close the door and verify the magnets attract each other. If they repel, flip one magnet over.
   - Once orientation is confirmed, apply a small drop of CA glue around the rim of each magnet to retain it.

6. Close the door. The magnets should hold it shut, and the foam weatherstrip should compress slightly around the perimeter.

---

### Step 16 — Install the Top Cap

**Parts:** `top_cap.stl`, `led_panel.stl`, `seed_box_lid.stl`
**Components:** SSD1306 OLED display (optional but recommended), 4× status LEDs with pre-attached resistors, buzzer (optional)

**What is the OLED display?** OLED stands for Organic Light-Emitting Diode. The SSD1306 is a small 0.96" screen (about 25×13 mm) that the device uses to show the current time, tray day numbers, water status, and moisture readings. It connects via I2C and is optional — the device functions fully without it, with status information available through the indicator LEDs.

1. Snap the **LED panel** (`led_panel.stl`) into the status panel recess in the top cap face.

2. Press the 4× indicator **LEDs** into the Ø3.5 mm holes in the LED panel:
   - Hole 1: Green LED (GPIO 18 via 330Ω) — heartbeat / system OK
   - Hole 2: Yellow LED (GPIO 19 via 330Ω) — water low
   - Hole 3: Red LED (GPIO 5 via 330Ω) — Tray A harvest ready
   - Hole 4: Red LED (GPIO 17 via 330Ω) — Tray B or Tray C harvest ready

   Route each wire down through the ring cable channels to the ESP32.

3. **OLED display (optional):** Seat the SSD1306 module into the OLED window recess. Connect via a 4-wire JST-XH cable to the ESP32:

   | OLED pin | Connects to |
   |---------|-------------|
   | VCC | 3.3V |
   | GND | GND |
   | SDA | ESP32 GPIO 21 (shared I2C bus with RTC) |
   | SCL | ESP32 GPIO 22 (shared I2C bus with RTC) |

   > Both the RTC module and OLED share the same I2C bus on GPIO 21 and 22. This is normal — I2C is designed for multiple devices on one bus, each with a unique address.

4. Install the optional **buzzer** in the top cap buzzer pocket. Connect + to GPIO 16 via 100Ω resistor; − to GND.

5. Route all wires from the top cap components down through the ring cable channels to the ESP32 in the base.

6. **Stack the top cap** on ring 3: align the 6× flange bolt holes and use 6× M3×20 mm bolts.

7. Install the seed storage box and its lid in the top cap seed compartment.

---

### Step 16a — Install Ventilation Fan and Switch (Optional but Recommended)

**What this step does:** Adds a 40mm exhaust fan to the top cap top surface and a toggle switch on the top cap front face. The fan exhausts humid air upward out of the growing column, reducing mold risk. It is completely manual — no relay, no firmware — just a toggle switch in series with the fan.

**Components:** 40mm 12V brushless fan (E30), SPST mini toggle switch (E31), 40mm fan guard/grill (E32), 40mm PC fan dust filter (E33)
**Hardware:** 4× M3×12mm bolts, 4× M3 hex nuts
**Wire:** 30cm 20AWG red wire, 30cm 20AWG black wire

> **Skip this step** if you are building without the fan. The top cap functions fully without it — the pre-printed exhaust hole will simply remain open (or you can cover it with a small PETG cap printed from a short cylinder).

#### Fan installation:

1. Orient the **40mm fan** with the **label side** (which shows the model number and rotation arrow) facing **downward into the cap** — this is the **inlet** side. The smooth side with the hub faces up and exhausts upward.

2. Align the fan's four corner bolt holes with the **4× M3 mounting holes** in the top cap top surface (at the corners of a 32×32mm square centred on the exhaust hole).

3. Lower the fan into the **2mm recess** in the top cap top surface. The fan body should sit flush or slightly recessed.

4. Insert **4× M3×12mm bolts** through the fan corner holes from above, into the M3 hex nuts below. Tighten with a screwdriver until snug — do not overtighten (PETG will crack if the bolt is overtightened).

5. Place the **40mm foam dust filter** (E33) over the fan's top (exhaust) face, centred on the fan frame. Then snap the **fan guard/grill** (E32) over it, sandwiching the filter against the fan. The guard retains the filter and prevents blade contact; the filter blocks insects (including fungus gnats) from entering the column through the fan hole when the fan is not running.

#### Switch installation:

6. Insert the **toggle switch body** into the **6.5mm panel-cut hole** on the top cap front face (right side of the front face, approximately 25mm from the right edge).

7. From inside the cap, thread the **toggle switch retaining nut** onto the switch body and tighten until the switch flange presses against the outer face.

8. The switch should toggle cleanly between ON and OFF positions with a positive click.

#### Wiring:

9. Connect the fan circuit with 20AWG wire:

   ```
   12V bus (stripboard) ──► 20 AWG red ──► SW2 input terminal
   SW2 output terminal ──► 20 AWG red ──► Fan red (+) wire
   Fan black (−) wire ──► 20 AWG black ──► GND bus (stripboard)
   ```

   > The toggle switch is wired in the positive (red) lead. When the switch is ON, 12V reaches the fan and it spins. When OFF, the fan is completely unpowered.

10. Route the wiring down through the ring cable channels to the stripboard in the electronics bay. Secure with tube clip saddles or cable ties every 100mm.

11. **Test:** With the device powered (12V connected), flip the toggle switch to ON. The fan should spin immediately and you should feel airflow from the top. Flip to OFF — fan stops. If the fan does not spin, check polarity and the switch wiring.

---

### Step 17 — Pre-Power Electrical Check

Complete all of the following before connecting any 12 V power supply.

1. **Fuse check:** Confirm the 5 A blade fuse is installed in the inline fuse holder.

2. **Buck converter voltage:** With a multimeter set to DC Voltage, confirm the buck converter output reads 5.0 V before the ESP32 is connected. If needed, reconnect the 12 V supply temporarily and re-adjust.

3. **Relay module check:**
   - VCC pin connected to 3.3V (not 5V)
   - JD-VCC pin connected to 5V from the buck converter
   - GND connected to common ground
   - JD-VCC jumper is absent (removed in Step 2)

4. **GPIO wiring check:** Trace each signal wire from the ESP32 GPIO pin to confirm:
   - IN1 → GPIO 26 (LED Tray A)
   - IN2 → GPIO 27 (LED Tray B)
   - IN3 → GPIO 25 (LED Tray C) — not GPIO 14
   - IN4 → GPIO 13 (Pump) — not GPIO 12
   - Float switch: one wire to GPIO 33, one wire to GND
   - Moisture sensor A: AOUT to GPIO 34, VCC to 3.3V
   - Moisture sensor B: AOUT to GPIO 35, VCC to 3.3V
   - Moisture sensor C: AOUT to GPIO 32, VCC to 3.3V
   - Green LED: GPIO 18 via 330Ω
   - Yellow LED: GPIO 19 via 330Ω
   - Red LED A: GPIO 5 via 330Ω
   - Red LED B/C: GPIO 17 via 330Ω
   - Buzzer: GPIO 16 via 100Ω
   - RTC SDA: GPIO 21; RTC SCL: GPIO 22
   - OLED SDA: GPIO 21 (shared); OLED SCL: GPIO 22 (shared)

5. **Continuity check:** Set multimeter to continuity mode (beeps when touching). Check that there is no short circuit between the +12V bus and GND. This catches wiring errors before they blow the fuse or damage components.

6. **Polarity check:** Trace every red wire to confirm it connects to a positive terminal. Trace every black wire to confirm it connects to ground.

7. If all checks pass, connect the 12 V power supply. The green LED should illuminate. The OLED (if installed) should show startup text within 2 seconds.

---

### Step 18 — Flash Firmware and Set the Clock

See `docs/04-software/installation-guide.md` for the full step-by-step guide.

**Summary:**

1. On your computer, install **Arduino IDE 2.x**.
2. Add ESP32 board support (paste the Espressif URL into Arduino IDE Preferences → Additional Board URLs).
3. Install three libraries: **RTClib**, **Adafruit GFX Library**, **Adafruit SSD1306**.
4. Open `software/firmware/microgreen_controller/microgreen_controller.ino`.
5. Select Board: **ESP32 Dev Module**; select the correct USB port.
6. Click **Upload**. The firmware compiles and flashes to the ESP32.
7. Open **Serial Monitor** at **115200 baud**.
8. Find the current Unix timestamp at [https://www.unixtimestamp.com](https://www.unixtimestamp.com). Type `T` followed immediately by the number (e.g., `T1739836800`) and press Enter. The device confirms the time is set.
9. Type `S` and press Enter to read the status dump. Confirm the time is correct.

> **What is a Unix timestamp?** It is a number representing the number of seconds since 1 January 1970. It is a universal way to communicate time precisely. The device converts this to a human-readable date and time internally.

---

### Step 19 — Water Fill and Leak Test

1. Remove the **reservoir lid** by unscrewing it. Pour **2 litres of clean tap water** into the reservoir. Replace and tighten the lid.

2. Set the device on dry paper towels. Leave for **24 hours** undisturbed.

3. Inspect the paper towels. If completely dry, all reservoir seals are good — proceed.

4. If the paper towels are damp anywhere:
   - Drain the reservoir (unscrew the lid and carefully tilt the base over a sink)
   - Leave to dry for 24 hours
   - Apply another coat of XTC-3D to the suspect seam inside the reservoir
   - Cure for 24 hours
   - Refill and re-test

5. **Manual pump test:** With the reservoir filled, the device powered, and the serial monitor open, temporarily add `run_pump(true);` to the top of `loop()` in `microgreen_controller.ino`, re-flash, and observe whether water is delivered from all three drip emitters into each tray level. Confirm all three drip emitters flow. Then remove the test line and re-flash the final firmware.

> See `docs/04-software/installation-guide.md` Step 11 for the full pump calibration procedure.

---

### Step 20 — Seed Your First Tray

You will only seed Tray A (bottom ring) today. Trays B and C are seeded 3 and 6 days later, creating a staggered rotation so you harvest one tray every 3 days instead of three trays all at once.

1. Expand one **compressed coir puck**: place it in a bowl and pour 300–400 mL of water over it. Wait 5 minutes. It will expand from a compressed disc to about 8× its original volume. Break it apart with your fingers until it is loose and fluffy. It should feel like slightly damp compost, not soggy.

2. Spread the **expanded coir** across the bottom of the Tray A growing tray to approximately **2 cm depth**. Spread it evenly — thin spots will dry out faster.

3. **Soak the seeds:** Measure 12–15 g of broccoli microgreen seeds (about 1.5 tablespoons). Place in a small glass, cover with 50 mL of cool water, and leave for **4–8 hours** (soak overnight if convenient). The seeds absorb water and become slightly sticky and swollen — this is correct.

4. After soaking, drain the seeds through a fine-mesh strainer. Spread them **evenly** over the coir surface in a single layer. Every part of the coir surface should have seeds, but they should not pile up or clump.

5. Slide the **growing tray** into Tray A's ring level and push the ring door closed.

6. Push the **moisture sensor probe** for Tray A gently into the coir at one corner of the tray, about 2 cm deep. Do not bend the probe — it will crack.

7. **Press the BOOT button** on the ESP32 once. This is the button labelled "BOOT" or "IO0" on the ESP32 board — typically the button nearest the USB connector.
   - **Three slow green LED flashes** = Tray A seeded successfully ✓
   - **Five rapid red flashes** = all trays are already active (unexpected on first use — check tray states via serial `S` command)
   - The OLED will display: `A: D00 germinating`

8. **Days 0–2:** The lights for Tray A will remain **off** automatically. This is the germination blackout — broccoli seeds germinate best in darkness. Leave the door closed.

9. **Day 3:** Lights will turn on automatically at 06:00. You should see the grow strip glow through the door.

10. **Days 3 and 6:** Seed Trays B and C by repeating Steps 20.1–20.7 for each tray (press BOOT once per tray, in order B then C).

11. **Day 8 (from Tray A seeding):** The red LED for Tray A illuminates and the buzzer sounds once. Tray A is ready to harvest. See `docs/04-software/user-manual.md` for harvesting and cleaning instructions.

---

## Completion Checklist

Before declaring the device ready for operation, confirm every item:

**Waterproofing and sealing:**
- [ ] Reservoir interior — XTC-3D coated, two coats, 24h water test passed
- [ ] Waste chamber interior — XTC-3D coated
- [ ] All three sub-trays — XTC-3D coated, two coats, 24h water test passed
- [ ] Base unit halves joined with M3 bolts and RTV silicone on water-zone seam
- [ ] M5 heat-set inserts installed at 4 base corners

**Reservoir:**
- [ ] O-ring seated in reservoir lid groove
- [ ] ZP2508 float switch body threaded through lid gland, gland nut tightened
- [ ] Reservoir lid fitted and snug on fill-port boss
- [ ] Float switch wires routed to electronics bay

**Power management:**
- [ ] Buck converter output confirmed at 5.0V before ESP32 connection
- [ ] DC barrel jack installed in left outer wall
- [ ] 5A fuse installed in inline fuse holder
- [ ] Reverse polarity protection installed

**Electronics:**
- [ ] ESP32 mounted on stripboard
- [ ] CR2032 coin cell installed in DS3231 RTC module
- [ ] RTC SDA → GPIO 21; SCL → GPIO 22; VCC → 3.3V
- [ ] JD-VCC jumper REMOVED from relay module (Critical)
- [ ] Relay VCC → 3.3V; JD-VCC → 5V; GND → GND
- [ ] Relay IN1 → GPIO 26 (LED Tray A)
- [ ] Relay IN2 → GPIO 27 (LED Tray B)
- [ ] Relay IN3 → GPIO 25 (LED Tray C — not GPIO 14)
- [ ] Relay IN4 → GPIO 13 (Pump — not GPIO 12)
- [ ] Float switch: one wire GPIO 33, one wire GND
- [ ] Moisture sensor A: AOUT → GPIO 34; VCC → 3.3V
- [ ] Moisture sensor B: AOUT → GPIO 35; VCC → 3.3V
- [ ] Moisture sensor C: AOUT → GPIO 32; VCC → 3.3V
- [ ] Green LED GPIO 18 via 330Ω
- [ ] Yellow LED GPIO 19 via 330Ω
- [ ] Red LED A GPIO 5 via 330Ω
- [ ] Red LED B/C GPIO 17 via 330Ω
- [ ] Buzzer GPIO 16 via 100Ω (optional)
- [ ] OLED SDA → GPIO 21; SCL → GPIO 22 (optional)

**Mechanical:**
- [ ] All 3 rings assembled from quarter-sections with RTV at seams
- [ ] Foam weatherstrip on all ring flange faces (top and bottom of each ring)
- [ ] All 3 rings stacked and bolted to base and to each other (6× M3×20mm per joint)
- [ ] All 3 sub-trays waterproofed and inserted on lower ledge rails
- [ ] All 3 growing trays inserted on upper ledge rails
- [ ] Waste drain tubes connected to all 3 sub-tray drain fittings
- [ ] LED brackets installed at ~100mm above tray surface in each ring
- [ ] LED strips wired to relay CH1/CH2/CH3 with correct polarity
- [ ] Moisture sensor cables routed through ring cable channels
- [ ] All 3 doors hinged with weatherstrip and magnet catches
- [ ] Top cap installed with status LEDs, OLED (optional), and seed storage

**Pump and tubing:**
- [ ] Pump mounted and wired to relay CH4
- [ ] 3-way manifold installed on pump outlet
- [ ] 3 supply tubes routed from manifold to tray drip ports, secured with clips
- [ ] 3 drip emitters installed at tray drip ports
- [ ] 3 waste tubes routed from sub-tray drain fittings to waste chamber

**Ventilation (if installed):**
- [ ] 40mm fan seated in top cap recess, label/inlet side facing INTO cap
- [ ] Fan secured with 4× M3×12mm bolts into M3 hex nuts
- [ ] Foam dust filter (E33) placed on exhaust (top) face of fan
- [ ] Fan guard (E32) snapped over filter on exhaust face — filter sandwiched between fan and guard
- [ ] Toggle switch mounted in 6.5mm panel-cut hole on top cap front face (right side)
- [ ] Fan wiring: 12V bus → switch input → switch output → fan red (+) → fan black (−) → GND
- [ ] Fan test: switch ON → fan spins; switch OFF → fan stops

**Insect protection:**
- [ ] 6× fiberglass mesh patches (E34, 27×10mm) cut from sheet
- [ ] One mesh patch adhered with RTV silicone over interior of each ring vent slot (2 slots × 3 rings = 6 patches)
- [ ] RTV cured before stacking rings
- [ ] Foam dust filter fitted under fan guard (see Ventilation above)

**Firmware and testing:**
- [ ] Firmware flashed via Arduino IDE
- [ ] RTC clock set via `T<epoch>` serial command
- [ ] Serial `S` status dump shows correct time and tray states
- [ ] Manual pump test: water reaches all 3 drip emitters
- [ ] Reservoir 24h leak test passed
- [ ] Tray A seeded; BOOT button pressed; three green flashes confirmed

---

## Troubleshooting

| Symptom | Likely cause | Action |
|---|---|---|
| Green LED does not light after power-on | Blown fuse, wrong supply polarity, buck converter voltage wrong | Check fuse; verify 12V supply polarity; re-check buck converter |
| ESP32 resets every few seconds | Relay JD-VCC jumper not removed; buck converter out of spec | Confirm jumper removed; re-check buck converter output at 5.0V |
| Yellow LED always on immediately | Float switch wiring error, or reservoir empty | Check float switch wires at GPIO 33 and GND; fill reservoir |
| Relay clicks but LED strip does not light | LED strip polarity reversed, or wired to COM not NO | Check strip + wire connects to relay NO; check strip polarity marking |
| Relay fires but pump does not run | Pump wired to COM not NO, or pump faulty | Move pump + wire to relay CH4 NO contact |
| OLED shows nothing | I2C address mismatch (try 0x3D) or wiring error | Check SDA/SCL wiring; try `#define OLED_I2C_ADDR 0x3D` in config.h and re-flash |
| Moisture sensor reads 0% always | Sensor VCC not connected, or wrong ADC pin | Check VCC → 3.3V and correct GPIO |
| Moisture sensor reads 100% in dry air | MOISTURE_DRY_RAW value too low | Calibrate per installation-guide.md Step 10 |
| Reservoir seeps at base seam | RTV seal insufficient or not cured before water contact | Drain, dry 24h, re-apply RTV to seam, cure 24h, re-test |
| Sub-tray overflows to ring floor | Pump run time too long, or waste drain tube blocked | Reduce PUMP_RUN_SECONDS in config.h; check waste tube is not kinked |
| Door does not close flush | Hinge pin binding, or magnet polarity reversed | Ream hinge hole with 3mm bit; flip one magnet to correct polarity |
| No text in Serial Monitor | Wrong baud rate (must be 115200) or charge-only USB cable | Set baud to 115200; use a data-capable USB cable |
| Clock shows 2000-01-01 after power-on | RTC was never set, or CR2032 is dead | Set clock via `T<epoch>` serial command; replace CR2032 coin cell |
| Five red LED flashes on button press | All three trays already have active grow cycles | Wait until a tray reaches day 10+ before pressing the BOOT button again |
| Water not reaching all three trays | Tubing kinked, drip emitter blocked | Straighten tubing; clear 2mm drip emitter orifice with a pin |

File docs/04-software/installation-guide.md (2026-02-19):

# Firmware Installation Guide

**Phase:** 04 Software
**Status:** Complete
**Last Updated:** 2026-02-18
**Firmware:** `software/firmware/microgreen_controller/`

---

## Overview

The microgreen box runs firmware on an ESP32-WROOM-32 microcontroller written for the Arduino framework. This guide covers installing the required tools, flashing the firmware, setting the clock, and calibrating the moisture sensors.

---

## Prerequisites

- Hardware fully assembled per [assembly-instructions.md](../03-build/assembly-instructions.md)
- Wiring verified per [wiring-schematic.md](../../hardware/schematics/wiring-schematic.md)
- A computer with a USB port and internet access
- A micro-USB data cable (not charge-only — must carry data)

---

## Step 1: Install Arduino IDE

Download and install **Arduino IDE 2.x** from [https://www.arduino.cc/en/software](https://www.arduino.cc/en/software).

Arduino IDE 2.x is recommended. IDE 1.8.x also works.

---

## Step 2: Add ESP32 Board Support

1. Open Arduino IDE → **File → Preferences**
2. In "Additional boards manager URLs" add:
   ```
   https://raw.githubusercontent.com/espressif/arduino-esp32/gh-pages/package_esp32_index.json
   ```
3. Click OK
4. Go to **Tools → Board → Boards Manager**
5. Search for `esp32` and install **"esp32" by Espressif Systems** (version 2.x or later)

---

## Step 3: Install Required Libraries

Go to **Tools → Manage Libraries** and install these three libraries:

| Library | Author | Purpose |
|---|---|---|
| `RTClib` | Adafruit | DS3231 real-time clock |
| `Adafruit GFX Library` | Adafruit | OLED graphics primitives |
| `Adafruit SSD1306` | Adafruit | OLED display driver |

Search for each by name and click **Install**. Accept any dependency prompts.

---

## Step 4: Open the Firmware Sketch

1. In Arduino IDE: **File → Open**
2. Navigate to:
   ```
   microgreen-box/software/firmware/microgreen_controller/
   ```
3. Open `microgreen_controller.ino`

The sketch and `config.h` will open as two tabs in the editor.

---

## Step 5: Configure Parameters

Open the `config.h` tab. Review the user-adjustable parameters and change any that differ from your setup.

The defaults that most commonly need adjustment:

| Parameter | Default | When to change |
|---|---|---|
| `PHOTO_ON_HOUR` | 6 | Shift light schedule to match your morning routine |
| `PHOTO_OFF_HOUR` | 20 | Adjust for different photoperiod length |
| `PUMP_RUN_SECONDS` | 90 | **Must be calibrated** — see Step 9 |
| `MOISTURE_DRY_RAW` | 3200 | **Must be calibrated** — see Step 8 |
| `MOISTURE_WET_RAW` | 1200 | **Must be calibrated** — see Step 8 |

See [requirements.md](requirements.md) for a full explanation of every parameter.

---

## Step 6: Select Board and Port

1. Connect the ESP32 to your computer via micro-USB
2. In Arduino IDE:
   - **Tools → Board → esp32 → ESP32 Dev Module**
   - **Tools → Port** → select the port that appeared when you connected the ESP32
     - Linux: `/dev/ttyUSB0` or `/dev/ttyACM0`
     - macOS: `/dev/cu.usbserial-*`
     - Windows: `COM3`, `COM4`, etc.

If no port appears:
- Windows/macOS: install the CP2102 USB-UART driver from Silicon Labs
- Linux: add your user to the `dialout` group (`sudo usermod -aG dialout $USER` then log out/in)

---

## Step 7: Flash the Firmware

1. Click the **Upload** button (right-arrow icon) in Arduino IDE
2. If the upload fails with "Connecting..." stuck: hold the **BOOT** button on the ESP32, click Upload, release BOOT once "Uploading..." appears
3. Wait for "Done uploading."

The ESP32 restarts automatically after flashing.

---

## Step 8: Verify Startup

Open **Tools → Serial Monitor**. Set baud rate to **115200** and line ending to **Newline**.

You should see:
```
=== Microgreen Box v1.0 ===
EEPROM: first boot — defaults written
RTC OK: 2026-02-18 00:00:00
OLED OK
Setup complete. Entering main loop.
```

**If you see errors:**

| Message | Action |
|---|---|
| `ERROR: DS3231 not detected` | Check I2C wiring on GPIO21 (SDA) and GPIO22 (SCL); check 3.3 V and GND to RTC module |
| `OLED: not detected` | Optional — device works without it; check wiring if display is installed |
| No output at all | Check micro-USB cable is data-capable; check CP2102 driver |
| Wrong time shown | Proceed to Step 9 to set the clock |

---

## Step 9: Set the Real-Time Clock

If the time shown is wrong (RTC lost power, or first use), set it via serial:

1. Find the current Unix epoch timestamp at [https://www.unixtimestamp.com](https://www.unixtimestamp.com)
2. In the Serial Monitor, type `T` followed immediately by the epoch number (no spaces), e.g.:
   ```
   T1739836800
   ```
3. Press Enter (Send). The RTC responds:
   ```
   RTC set to 1739836800
   ```
4. Verify by typing `S` and reading the time in the status dump.

The DS3231 has a CR2032 coin cell backup — once set, the time is maintained indefinitely through power cycles.

---

## Step 10: Calibrate Moisture Sensors

The capacitive moisture sensor raw ADC values vary between individual sensor units. Calibration is required once after assembly.

**You will need:** a cup of clean water and a dry surface.

### Calibration Procedure

Run this for each sensor one at a time (or all three if values are similar):

1. With the device powered and serial monitor open, type `S` + Enter to see current readings.
2. Hold **Sensor A** (connected to GPIO34) in open air for 10 seconds. Note the moisture % shown.
   - A high raw ADC count maps to 0 % moisture in the default config.
   - If the displayed moisture reads significantly above 0 % in dry air, the `MOISTURE_DRY_RAW` value needs to be increased.
3. Submerge just the sensing tip (bottom 3 cm) of Sensor A in the cup of water. Wait 5 seconds. Note the reading.
   - Should read close to 100 %. If lower, `MOISTURE_WET_RAW` needs to be decreased.

### Getting Raw ADC Counts

To see raw ADC values, temporarily add this to the top of `loop()` in the sketch:
```cpp
Serial.printf("A_raw=%d  B_raw=%d  C_raw=%d\n",
              analogRead(PIN_MOISTURE_A),
              analogRead(PIN_MOISTURE_B),
              analogRead(PIN_MOISTURE_C));
```

Flash, open serial monitor, and read the raw counts:
- Record the value in **dry air** → set as `MOISTURE_DRY_RAW` in `config.h`
- Record the value **submerged** → set as `MOISTURE_WET_RAW` in `config.h`
- Remove the debug line, re-flash

**Typical values for 3.3 V-powered Capacitive V1.2:**

| Condition | Typical raw count |
|---|---|
| Dry air | 2900–3400 |
| Wet coir (field capacity) | 1800–2200 |
| Fully submerged | 900–1400 |

---

## Step 11: Calibrate Pump Run Time

The pump delivers approximately 50–100 mL/min depending on tubing length and head pressure.

1. Fill the reservoir with water
2. Hold a measuring cup under the drip manifold output
3. In serial monitor, type `S` to confirm system state
4. Temporarily add `run_pump(true);` at the top of `loop()`, flash, and observe how much water is delivered in `PUMP_RUN_SECONDS`
5. Adjust `PUMP_RUN_SECONDS` in `config.h` until each pump run delivers ~75 mL (25 mL × 3 trays)
6. Remove the test line and re-flash

---

## Step 12: Start the First Growing Cycle

With firmware running and RTC set:

1. Fill the reservoir with clean water
2. Prepare Tray A: expand a coir puck with water, fill the growing tray, and sow 12–15 g of pre-soaked broccoli seed
3. Press the **BOOT button** (GPIO0) once
   - Three green LED flashes confirm Tray A is seeded
   - OLED shows "A: D00 germinating"
4. Days 0–2: lights remain off automatically (germination blackout)
5. Day 3: lights activate on the photoperiod schedule
6. Day 7 and 10: repeat button press for Trays B and C (staggered rotation)
7. Day 8+: red LED activates and buzzer sounds once for Tray A — harvest ready

---

## Troubleshooting

| Problem | Likely cause | Fix |
|---|---|-----|
| Relay clicks but load doesn't activate | JD-VCC jumper still in place | Remove the VCC–JD-VCC shorting jumper on relay board |
| ESP32 resets when relay fires | JD-VCC not isolated; coil inrush on ESP32 rail | Remove jumper; power JD-VCC from 5 V bus separately |
| Moisture always reads 0 % | Sensor not powered or wrong pin | Check 3.3 V and GND to sensor; confirm ADC pin in config.h |
| Moisture reads 100 % in dry air | MOISTURE_DRY_RAW too low | Recalibrate (Step 10) |
| Lights don't turn on | Relay LOW-level trigger not set | Set relay module to LOW-level trigger mode |
| Lights on during germination | BLACKOUT_DAYS set to 0 | Set `BLACKOUT_DAYS 2` in config.h |
| No OLED output | OLED I2C address mismatch | Try `#define OLED_I2C_ADDR 0x3D` in config.h |
| RTC shows 2000 after power loss | Dead coin cell | Replace CR2032 on DS3231 module |
| "No tray available to seed" flashes red | All trays are active | Wait for a tray to reach day ≥ 10 before pressing button |
| Serial monitor shows garbage | Wrong baud rate | Set serial monitor to 115200 baud |

---

## I2C Address Scanner

If you are unsure of I2C addresses on your modules, flash this standalone sketch to scan the bus:

```cpp
#include <Wire.h>
void setup() {
    Serial.begin(115200);
    Wire.begin(21, 22);
    for (byte a = 1; a < 127; a++) {
        Wire.beginTransmission(a);
        if (Wire.endTransmission() == 0)
            Serial.printf("Found device at 0x%02X\n", a);
    }
    Serial.println("Scan complete");
}
void loop() {}
```

Expected output:
```
Found device at 0x3C   ← SSD1306 OLED
Found device at 0x57   ← AT24C32 EEPROM on DS3231 module
Found device at 0x68   ← DS3231 RTC
```

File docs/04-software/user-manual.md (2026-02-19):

# User Manual

**Phase:** 04 Software
**Status:** Complete
**Last Updated:** 2026-02-18
**Applies to:** Microgreen Box v1.0

---

## Overview

The Microgreen Box grows broccoli microgreens automatically. It controls its own lighting schedule, waters the plants twice a day, monitors soil moisture, and tells you when a tray is ready to harvest. Your job is simple: press a button when you seed a tray, refill the water reservoir when prompted, and harvest when the red LED lights up.

This manual covers everything you need to operate the device. No electronics knowledge is required.

**What you need each week:**
- Approximately 15 minutes per tray to clean, sow, and reseed (every 3 days)
- 5 minutes to harvest
- Water top-up approximately once every 10–14 days

---

## Understanding the Controls

### The BOOT Button

The BOOT button (labelled "BOOT" or "IO0" on the ESP32 board, typically near the USB port) is the only control you use during normal operation. A single press seeds the next available tray.

- **Three slow green flashes** = tray seeded successfully
- **Five rapid red flashes** = all three trays are currently growing; no tray is available to seed

### The Status LEDs

Four LEDs on the top cap show system status at a glance:

| LED colour | Normal behaviour | Meaning when lit or changed |
|---|---|---|
| Green | Blinks once per second | System is running normally |
| Green | Blinks rapidly (5× per second) | An alarm is active — check yellow or red LEDs |
| Yellow | Off when OK | Water reservoir is low — refill now |
| Red (Tray A) | Off during growing | Tray A is ready to harvest |
| Red (Tray B/C) | Off during growing | Tray B or Tray C (or both) is ready to harvest |

### The Buzzer (if installed)

- **Two short beeps** when the device first detects low water — then silent until refilled
- **One short beep** when a tray first reaches harvest day — then silent until harvested and reseeded

### The OLED Display (if installed)

The 0.96" display shows six lines of status information:

```
14:32  OK
Water: FULL
A: D08 HARVEST!
B: D05 growing
C: D02 germinate
Pump: 07:00 done
```

- Line 1: current time and overall system status
- Line 2: reservoir status (FULL / LOW)
- Lines 3–5: tray A, B, C — day number and current stage
- Line 6: next scheduled pump event and whether today's events have fired

**Tray stages shown:**
- `D00 germinating` — Days 0–2, lights off, seeds sprouting in darkness
- `D03 growing` — Lights on, seedlings growing
- `D08 HARVEST!` — Harvest day reached, red LED lit
- `---` — Tray is empty (not yet seeded)

### Serial Monitor (for setup and diagnostics)

Connect the device to a computer via USB and open the Serial Monitor at **115200 baud**. Two commands are available:

| Command | Example | Effect |
|---|---|---|
| `T<epoch>` | `T1739836800` | Set the clock to the given Unix timestamp |
| `S` | `S` | Print a full status dump: time, tray states, moisture readings, pump log, alarm flags |

Get the current Unix timestamp at [https://www.unixtimestamp.com](https://www.unixtimestamp.com).

---

## Initial Setup

These steps are done once when you first assemble the device, and again after any extended power-off period where the clock might lose its time.

### Step 1 — Set the Clock

The device keeps time using a DS3231 real-time clock module with a CR2032 battery backup. Once set, the clock runs even if the main power is disconnected. You only need to set it again if the coin cell runs flat (typically after 2–5 years).

1. Connect the ESP32 to your computer via the USB cable.
2. Open the Arduino IDE Serial Monitor (or any serial terminal) at **115200 baud**.
3. Open [https://www.unixtimestamp.com](https://www.unixtimestamp.com) in a browser — note the current Unix timestamp (a large number, e.g., 1739836800).
4. In the serial monitor, type `T` immediately followed by the timestamp number (no space or gap), e.g.:
   ```
   T1739836800
   ```
5. Press Enter. The device responds: `RTC set to 1739836800`
6. Type `S` and press Enter. Confirm the time shown in the status dump is correct.

> Once set, the device does not need a computer connection to operate. Disconnect the USB cable after setup is complete.

### Step 2 — Calibrate Moisture Sensors

The three capacitive moisture sensors each have slightly different electrical characteristics from the factory. Calibration ensures the moisture percentage readings are accurate for your specific sensors.

See `docs/04-software/installation-guide.md` Step 10 for the full calibration procedure. In brief:

1. Hold each sensor in dry air; note the raw ADC value shown in the serial monitor.
2. Submerge the sensing tip in clean water; note the raw ADC value.
3. Update `MOISTURE_DRY_RAW` and `MOISTURE_WET_RAW` in `config.h` and re-flash.

Default values (3200 dry, 1200 wet) are reasonable approximations for the Capacitive V1.2 sensors and will work without calibration, but calibrated values give more accurate skip/top-up behaviour.

### Step 3 — Calibrate the Pump

The pump delivers approximately 75 mL total per watering event (25 mL per tray). The exact run time needed depends on your pump's flow rate, tubing length, and reservoir height.

See `docs/04-software/installation-guide.md` Step 11 for the calibration procedure. The default `PUMP_RUN_SECONDS = 90` targets a pump flow rate of about 50 mL/min. If your pump is faster, reduce this value; if slower, increase it.

---

## Starting a Grow Cycle

### How the rotation works

The device supports three growing trays labelled A (bottom ring), B (middle ring), and C (top ring). Trays are seeded on different days so you always have one tray ready to harvest approximately every 3 days:

| Day | Event |
|-----|---|
| Day 0 | Seed Tray A — press BOOT once |
| Day 3 | Seed Tray B — press BOOT once |
| Day 6 | Seed Tray C — press BOOT once |
| Day 8 | Tray A signals harvest ready (red LED + one buzzer beep) |
| Day 10 | Harvest Tray A. Clean tray. Seed again — press BOOT once. Tray A is now the new Day 0. |
| Day 11 | Tray B signals harvest ready |
| Day 13 | Harvest Tray B. Clean. Seed again. |
| Day 16 | Tray C signals harvest ready |
| Day 19 | Harvest Tray C. Clean. Seed again. |
| (repeat) | From this point, harvest one tray every ~3 days indefinitely |

> It takes about 3 weeks to establish the full rotation. After that, the device runs indefinitely on its own schedule.

### Seeding a tray

**Prepare the coir:**

1. Take one compressed coir puck (50 g, coconut-fibre growing medium).
2. Place it in a bowl and pour **300–400 mL of water** over it.
3. Wait 5 minutes — the puck expands to about 8× its original size. It will crumble apart as it absorbs water.
4. Break it apart with your fingers until it is loose and fluffy, like slightly damp potting compost.
5. Spread it evenly in the clean growing tray to approximately **2 cm depth**. Even depth prevents dry spots.

**Soak and sow the seeds:**

6. Measure **12–15 g of broccoli microgreen seeds** (roughly 1.5 tablespoons). Use seeds labelled "untreated", "organic", or "food grade" — avoid seeds coated with fungicide (common in garden-centre vegetable seeds).
7. Place seeds in a small glass, cover with water, and soak for **4–8 hours**. Overnight is convenient.
8. After soaking, pour through a fine-mesh strainer and shake out excess water. The seeds will be swollen and slightly sticky — this is correct.
9. Spread seeds **evenly over the coir surface** in a single layer. Cover the entire surface — every part of the coir should have seeds, but they should not pile up in clumps.
10. Slide the growing tray into the ring level and push the door closed.
11. Push the moisture sensor probe gently into the coir at one corner, about 2 cm deep. Do not bend the probe — it is fragile.

**Register the tray with the device:**

12. Press the **BOOT button** once.
    - Three slow green LED flashes = tray registered successfully
    - The device records the current timestamp as "Day 0" for this tray
    - OLED shows the tray at `D00 germinating`

> **Tip:** The device always seeds the next available tray in order A → B → C. If Tray A is empty, pressing BOOT registers Tray A. If A is active but B is empty, pressing BOOT registers Tray B. You do not need to select a specific tray.

---

## Daily Operation

The device runs automatically. You do not need to do anything each day unless an alarm activates.

### What the device does automatically

**Lighting:**
- Grow lights turn **ON at 06:00** and **OFF at 20:00** for each tray that has passed the germination period.
- For Days 0–2 after seeding, the lights for that tray remain **OFF** — this is the germination blackout. Darkness encourages faster, more even germination in broccoli. No physical cover is needed.
- Each tray's light is controlled independently. Tray A at day 5 can have its lights on while Tray C at day 1 keeps its lights off.

**Watering:**
- The pump runs at **07:00 and 19:00** each day.
- Before running, the device reads the moisture sensor of each active tray:
  - If all active trays read **above 70% moisture**: watering is **skipped** — the coir is still moist enough from the previous event.
  - Otherwise: the pump runs for 90 seconds, delivering approximately 25 mL to each tray.
- After 30 seconds settling time, moisture is re-read. If any tray reads **below 25%**: a short top-up run is triggered (30 seconds additional pump time).
- This feedback system prevents both over-watering (which causes mould) and under-watering (which wilts plants), even as water demand changes across the grow cycle.

**Alarms:**
- **Low water (yellow LED + two buzzer beeps):** The float switch in the reservoir detected low water. The alarm sounds once on first detection, then goes silent. Refill as soon as convenient.
- **Harvest ready (red LED + one buzzer beep):** A tray has reached Day 8. The buzzer sounds once. The red LED stays on until you harvest and reseed the tray, pressing BOOT to register the new cycle.

### Things to check occasionally

- **Water level:** Check the reservoir every 10–14 days. The 2.4 L reservoir provides approximately 13–16 days of watering at normal use (150 mL/day). The yellow LED tells you when it needs refilling.
- **Moisture readings:** Type `S` in the serial monitor to see current moisture percentages for all active trays. Readings should typically be in the 40–80% range during an active grow.
- **Waste chamber:** The waste chamber collects any overflow water from the sub-trays. Check and empty it approximately once per month (remove the waste chamber lid, which snap-fits and is hand-removable).

---

## Mold and Bacteria Prevention

The growing environment — warm, humid, enclosed — is also ideal for mold (*Pythium*, *Botrytis*) and bacterial biofilm. These are the primary causes of crop failure in microgreens. This section covers prevention procedures for each component of the system.

### Why mold happens

The two most common causes:

1. **Over-watering during germination.** Seeds are soaked for 4–8 hours before sowing, and the coir is already saturated on Day 0. Running the pump heavily on a freshly-seeded tray pushes the coir into anaerobic (oxygen-free) conditions at the root zone — the primary trigger for *Pythium* damping-off. The firmware addresses this: germinating trays (Days 0–2) are excluded from pump-trigger decisions. They still receive water when established trays need it, but they cannot trigger extra pump runs on their own.

2. **Poor airflow.** Stagnant humid air sitting on the coir surface allows mold spores to germinate. The ventilation fan and ring vent slots address this.

### Routine prevention — every grow cycle

**Coir preparation:**
- Rinse the dry coir puck briefly under a tap before expansion. This washes off surface dust and any salt residue from the compression process.
- Expand with clean water only. Do not use warm or stagnant water.
- Do not compress the expanded coir into the tray — spread it loosely to allow air in the gaps.

**Seed sanitation:**
- Before the 4–8 hour soaking soak, briefly rinse seeds in a **3% hydrogen peroxide solution** for 30 seconds (available from pharmacies, labelled as 3% H₂O₂). Pour into a fine-mesh strainer and rinse thoroughly under clean water.
- This step reduces surface mold spores and bacteria on the seed coat without harming germination. Broccoli seeds tolerate H₂O₂ rinses well.
- After the H₂O₂ rinse, proceed with the normal 4–8 hour clean water soak.

**Seeding density:**
- Spread seeds in a single even layer with no clumps. Dense seed piles block airflow at the surface and create mold focus points. Every seed should have contact with the coir surface.

### Reservoir maintenance — every 2–3 refills (~monthly)

1. Drain the reservoir completely (unscrew the lid, tilt the base over a sink).
2. Wipe the interior with a cloth dampened with a dilute cleaning solution: **1 teaspoon 3% H₂O₂ per 500 mL water**, or **1 teaspoon white vinegar per 500 mL water**.
3. Rinse the interior twice with clean water before refilling.
4. **Optional ongoing additive:** Add 1–2 mL of **3% food-grade hydrogen peroxide per litre** of reservoir water. This provides a mild antimicrobial effect in the water supply without harming the plants at this dilution. It breaks down to water and oxygen within hours.

### Tubing and manifold — monthly

1. Mix 500 mL of **1% H₂O₂ solution** (dilute 3% H₂O₂ with 2× water).
2. Pour into the reservoir and run the pump manually (via serial command or by temporarily increasing pump runtime) until the solution flows through all three drip emitters.
3. Follow with 500 mL of clean water to flush the H₂O₂ from the tubing.
4. Check the 2mm drip emitter orifices. If any emitter drips slowly or unevenly, clear the orifice with a thin pin. The 2mm hole is small enough to partially block with mineral deposits over time.

### Ventilation fan — when to use

The toggle switch on the top cap front face controls the 40mm exhaust fan. It exhausts warm humid air upward out of the column.

**Turn the fan ON if you observe:**
- White or grey fuzzy growth on coir surface (mold colonies)
- Persistent condensation on the ring interior walls
- A sour or musty smell from the growing chamber (distinct from the normal sulphur smell of broccoli)
- Ambient temperature above 28°C (vehicle in direct sun, summer operation)

**Normal operation:** Fan OFF. The passive ring vent slots (slide-cover slots on each ring's front and rear walls) provide sufficient airflow for normal conditions.

**Insect protection:** The fan hole is covered by a foam dust filter (under the fan guard) that blocks insects — including fungus gnats (~2mm), the primary microgreen pest — when the fan is not running. The ring vent slots are each covered by a permanent fiberglass mesh screen (adhered during assembly), which blocks insects regardless of whether the slide cover is in or out. You can safely leave the slide covers removed for ventilation without risk of insect entry.

**Outbreak response:** Remove the slide covers from the ring vent slots AND run the fan continuously until the mold resolves (usually 2–4 days). Reduce `PUMP_RUN_SECONDS` in config.h by 30% for the affected tray cycle.

**After an outbreak:** Clean the affected tray, sub-tray, and moisture sensor probe with the dilute H₂O₂ solution before reseeding.

### If mold is severe or recurring

- Check pump calibration. Type `S` in the serial monitor — if moisture readings are above 80% before a scheduled watering event, reduce `PUMP_RUN_SECONDS` in config.h.
- Check seed source. Mold-treated garden seeds (coated with fungicide or thiram) can transfer harmful chemistry to the growing medium. Use only untreated, organic, or food-grade microgreen seeds.
- Consider replacing the coir puck for the affected tray with a fresh one — spent coir from a mold outbreak retains spores.

---

## Temperature and Environment

The device has two separate temperature concerns: what the plants need, and what the hardware can tolerate. They have different limits.

### Plant temperature

| Ambient temperature | Effect on the grow |
|---|---|
| 20–22°C | Optimal. Best germination, even growth, full yield. |
| 18–24°C | Normal operating band — no impact on yield or timing. |
| 15–18°C | Acceptable. Germination may take 3–4 days instead of 2. Grow cycle may extend 1–2 days. |
| 25–27°C | Tolerated. Growth is slightly faster. Harvest on Day 8 rather than waiting to Day 10. |
| Below 12°C | Germination stalls. Seeds may sit for several days without sprouting. Growth becomes uneven. |
| Above 28°C sustained | Heat stress. Seedlings wilt between watering events; mold risk increases sharply. Open the ring vent slots and run the ventilation fan. |
| Above 32°C | Serious problem. Damping-off risk increases significantly; seedlings may fail to develop. |

> **Note:** The LED grow strips add approximately 2–4°C inside the growing chamber above the ambient temperature during the light period. If the room is already 26°C, the chamber interior during lights-on can be 28–30°C.

### Hardware temperature limits

#### High temperatures

The main risk at the high end is the PETG plastic, not the electronics. The ESP32 and relay module are rated to 85°C. PETG's glass transition temperature is 80°C, but under the sustained mechanical load of the stacked rings and full water reservoir, the printed parts can begin to creep and deform at temperatures above **55–60°C**.

The critical scenario is a vehicle in direct sun with windows closed — the interior can reach 60–80°C. A dark enclosure in direct sun is particularly at risk.

| Situation | Status |
|---|---|
| Ambient ≤35°C | Fully safe |
| Ambient 35–45°C, device in shade | Safe; monitor growing conditions |
| Vehicle, windows cracked, indirect sun | Typically 40–55°C — use the fan and open vent slots |
| Vehicle, direct sun, windows closed | 60–80°C possible — PETG deformation risk; move the device |

#### Low temperatures and freezing

The hard limit at the cold end is **0°C**. The electronics (ESP32, RTC) function down to −40°C and are not a concern. The water system is the risk.

| Situation | Risk |
|---|---|
| 5–15°C | Hardware fully safe; growing slows but continues |
| 0–5°C sustained | Pump, tubing, and manifold joints may partially freeze |
| Below 0°C | Water in the reservoir, tubing, and pump head can freeze and expand, cracking the PETG manifold or reservoir and damaging the pump head |

**If storing the device in a cold environment** (unheated garage, vehicle in winter): drain the reservoir and run the pump briefly to clear water from the tubing before temperatures drop below 0°C.

> If you use the optional LiFePO4 battery for off-grid power: the battery will not accept a charge below 0°C. Attempting to charge it in freezing conditions causes permanent damage to the cells. The battery can still *discharge* (power the device) down to around −20°C, but do not charge it until it has warmed above 0°C.

### Practical summary

| Ambient temperature | What to do |
|---|---|
| 18–24°C | Normal operation — nothing extra needed |
| 15–27°C | Fully operational; minor timing adjustments only |
| 28–35°C | Open ring vent slide covers + run ventilation fan; harvest on Day 8 |
| Above 35°C | Growing degrades; keep device out of direct sun |
| Above 55°C (enclosed vehicle, direct sun) | Move the device — PETG deformation risk |
| 0–5°C | Drain reservoir if temperature will be sustained; germination will fail |
| Below 0°C | Drain and store dry — do not leave water inside any component |

---

## Refilling the Reservoir

When the yellow LED illuminates or you notice the green LED is blinking fast (alarm active):

1. Unscrew the **reservoir lid** (on the top of the base unit, rear-left area).
2. Pour clean water into the reservoir — up to **2 litres** maximum.
3. Replace and tighten the lid.
4. The yellow LED turns off and the buzzer will not sound again until the next low-water event.

> **Optional — CalMag supplement:** From Day 3 of each tray's grow, you may add a small amount of liquid calcium-magnesium supplement (e.g., General Hydroponics CALiMAGic) to the reservoir water at a dose of 0.5 mL per litre. This partially compensates for the low mineral content of plain coconut coir. It is entirely optional — the device produces nutritious microgreens on plain water, and the primary health benefit (sulforaphane) is unaffected by mineral content.

---

## Harvesting

Broccoli microgreens are ready to harvest at **Day 8–10** from seeding. The device signals harvest at Day 8 with a red LED and one buzzer beep. You can harvest anytime between Day 8 and Day 10 — both flavour and nutritional content are optimal in this window.

### Signs of a ready tray

- The red harvest LED is lit
- Seedlings are 5–8 cm tall with two small leaves open (the cotyledons — the first leaves after germination, not the true broccoli leaves which appear later)
- Leaves have a healthy bright yellow-green colour under the grow strip

### Harvest procedure

1. Open the tray door and slide the **growing tray** out of the ring level.
2. Using **clean scissors or a sharp knife**, cut the microgreens just above the coir surface — approximately 5–10 mm from the base of the stems. Do not pull or uproot the plants.
3. You will harvest approximately **90–130 g** of greens from one tray (30 g per day for 3 days, or use all at once for freezing).
4. **Use immediately**, **refrigerate** (up to 7 days), or **freeze** (see the Consumption section below for details on each method).

> **Hygiene:** Wash hands before handling harvested greens. Do not wash the greens until you are ready to use them — surface moisture reduces refrigerator shelf life.

---

## Cleaning and Reseeding

### Clean the growing tray

1. Pull the spent coir and root mat out of the growing tray. The roots form a cohesive mat that usually lifts out in one piece.
2. Compost the spent coir and root mat — it is an excellent garden soil amendment.
3. Rinse the growing tray with clean water. Remove any remaining root fibres or seed husks.
4. If there is any visible mould or slime, wash with a dilute food-safe solution (1 tsp white vinegar in 500 mL water) and rinse thoroughly.
5. Allow to air dry for 10–15 minutes.

### Check and empty the sub-tray

1. Pull the sub-tray out of the ring level (it slides out from the front, same direction as the growing tray).
2. Check for accumulated water. A small amount of clear water is normal. Cloudy or smelly water may indicate over-watering — consider reducing `PUMP_RUN_SECONDS` in config.h.
3. Empty the sub-tray down a drain. Rinse briefly. Slide it back in and reconnect the waste drain tube (push-fit onto the rear drain barb).

### Clean the moisture sensor

Wipe the sensor probe gently with a damp cloth. Do not scrub the gold or black sensing pads near the tip. Allow to dry before reinserting into the new coir.

### Reseed the tray

Follow the seeding procedure in "Starting a Grow Cycle" above. After seeding and pressing BOOT once, the device immediately manages the new tray — lights off for days 0–2, then resuming the photoperiod schedule from day 3.

---

## Consuming Broccoli Microgreens for Maximum Health Benefit

### Why broccoli microgreens?

Broccoli microgreens contain exceptionally high concentrations of **glucoraphanin** (GRN), the stable precursor to **sulforaphane** (SFN). Sulforaphane is the key bioactive compound in broccoli — associated with cancer protection, anti-inflammatory activity, and activation of the body's cellular detoxification pathways (via the Nrf2 pathway). Broccoli microgreens contain 10–100 times more sulforaphane potential than mature broccoli.

**Target dose:** 30 g of fresh broccoli microgreens per day delivers approximately 190–220 µmol of sulforaphane — in the upper range of well-studied clinical doses (50–150 µmol/day is the evidence-based range).

### How sulforaphane is produced

Sulforaphane does not exist ready-made in the plant. It is produced by a chemical reaction when the plant is damaged:
- **GRN** (glucoraphanin) is stored stably in plant cells
- **Myrosinase** is an enzyme stored separately in the same cells
- When you **chew, chop, or blend** the greens, the cells rupture, GRN and myrosinase mix, and sulforaphane is produced within minutes

This means: **you must chew or blend the greens** — swallowing whole leaves produces very little sulforaphane. Chew each mouthful thoroughly (20–30 chews) if eating raw, or blend for 60 seconds if using a smoothie.

### Critical: heat destroys myrosinase

Myrosinase is destroyed by heat above **60–70°C**. Cooking, steaming, or adding microgreens to hot food eliminates most sulforaphane benefit. If you want to include microgreens in a cooked meal, add them after the dish has cooled below 60°C — or use the chop-and-wait technique: chop the greens, wait 40 minutes for sulforaphane to form, then add to food (the formed sulforaphane is heat-stable; only the myrosinase enzyme is heat-sensitive).

---

### Method 1: Morning Smoothie (Recommended)

The daily smoothie is the most practical and palatable method. Blending thoroughly ruptures all cells, maximising the GRN-to-SFN conversion. The flavour of broccoli microgreens (bitter, sulphurous) is **completely masked** by fruit in a well-made smoothie.

**Basic recipe (serves 1):**
- 30 g fresh or frozen broccoli microgreens (see frozen method below)
- 1 medium banana (frozen preferred — adds creaminess)
- 150 g frozen mixed berries (blueberry, blackberry, or dark berry mix work best)
- 200 mL water or oat milk

Blend on high for 60 seconds until completely smooth. Drink immediately.

**Flavour tips:**
- Dark berries (blueberry, blackberry) are most effective at masking the broccoli flavour.
- A tablespoon of peanut butter or almond butter adds richness and further suppresses any bitterness.
- A pinch of mustard seed powder (see below) can be added to boost sulforaphane production.
- The colour will be dark purple-green — this is normal.

> **Why smoothie rather than juice?** Juicing separates the juice from the plant fibres and cellular material, losing the myrosinase. Blending keeps everything, including all the enzymes. Smoothie = full benefit; cold-pressed juice = reduced benefit.

---

### Method 2: Eat Raw

If you prefer not to use a smoothie, eat the microgreens raw. Add to salads, grain bowls, sandwiches, or wraps at the end (not heated). Chew thoroughly — 20–30 chews per mouthful — to maximise cell disruption and sulforaphane production.

- The raw flavour is distinct but mild for broccoli — slightly spicy or mustard-like.
- An acidic dressing (lemon juice, white wine vinegar) pairs well and slightly enhances the reaction.
- Do not cook, blanch, or add to hot food.

---

### Method 3: Raw Freezing for Increased Sulforaphane

Freezing broccoli microgreens **raw and unblanched** at −20°C does not destroy sulforaphane — it actually **increases** myrosinase activity by 17–117% compared to fresh microgreens, resulting in up to **3.1× more sulforaphane** when blended.

> **Critical distinction from commercial frozen broccoli:** Commercial frozen broccoli is blanched (briefly boiled) before freezing to preserve colour and stop enzyme activity. This destroys myrosinase entirely. **Raw home freezing is completely different** — no heat is involved and the enzymes are preserved and enhanced by the freeze-thaw process.

**When to freeze:** Freeze surplus when a tray produces more than you can use in 7 days (90–130 g per tray). This allows you to bank several weeks of supply and consume on any schedule.

**Freezing procedure:**

1. Harvest the greens as normal.
2. Shake off any surface moisture. Do not wash before freezing (washing adds water that forms large ice crystals during freezing, damaging texture — this does not matter for blending, but avoid it regardless).
3. Divide into **30 g portions** and place each portion in a small zip-lock freezer bag.
4. Label each bag with the date and "raw broccoli microgreens". Write on the bag before adding the greens (the condensation from a cold bag makes it hard to write).
5. Seal and freeze at −20°C (standard home freezer). Freeze immediately — do not leave at room temperature or refrigerate first.

**Shelf life:** 3–6 months at −20°C. GRN content is fully preserved throughout storage. Myrosinase activity is maintained or enhanced.

**Consuming frozen microgreens:**

1. Take the bag directly from the freezer.
2. Break the frozen mass apart (hit the bag on the counter) and tip the frozen pieces into the blender.
3. Add other smoothie ingredients.
4. Blend immediately on high for 60 seconds — **do not thaw first.**

> **Why not thaw?** Thawing releases water rapidly, which dilutes the cell contents and allows the GRN-myrosinase reaction to begin in an uncontrolled way before blending properly mixes everything. Blending directly from frozen gives a more thorough cell disruption and better enzyme contact.

---

### Optional Enhancement: Mustard Seed Powder

Yellow mustard seeds contain very high concentrations of myrosinase. Adding a small amount to your smoothie provides "exogenous myrosinase" — enzyme from an outside source — which can supplement or substitute for the microgreens' own myrosinase if it has been reduced by storage.

- **Dose:** ¼ teaspoon (about 1 g) of ground yellow mustard seed — available as "dry mustard powder" or "mustard flour" in supermarkets or online
- **When to use:** Add to the blender with the other smoothie ingredients — especially useful when using older frozen microgreens (stored longer than 3 months) or if the greens were warmed before blending

---

### Consumption Summary Table

| Method | Daily effort | Palatability | SFN yield | Shelf life |
|---|---|---|---|---|
| Fresh smoothie | 5 min | Excellent (masked) | High | Drink immediately |
| Fresh raw | 0 min extra | Mild bitter flavour | High | Eat immediately |
| Fresh refrigerated | — | As above | High | 5–7 days at 4°C |
| Frozen then blended | 1 min to freeze; 5 min to blend | Excellent | Up to 3.1× fresh | 3–6 months |
| Cooked (>60°C) | — | N/A | Near zero | Avoid |

---

## Troubleshooting

### Yellow LED is on / buzzer beeped twice

**Cause:** Reservoir water level is low.

**Action:** Refill the reservoir with up to 2 litres of clean water (unscrew the reservoir lid, fill, replace lid). The yellow LED turns off as soon as the float switch detects water at the correct level.

If the LED stays on after refilling:
- Confirm the reservoir lid is fully tightened
- The float switch ball may be stuck — open the reservoir lid and check that the float ball hangs freely and moves up and down smoothly with water level changes
- Check the float switch wire connections at GPIO 33 and GND (see assembly instructions Step 9)

---

### Red LED is on — tray is at harvest day

**Cause:** Normal — the device has detected that a tray reached Day 8.

**Action:** Harvest the tray when convenient (any time between Day 8 and Day 10). After harvesting, clean the tray and reseed it, then press BOOT once to register the new Day 0. The red LED turns off when the new seed epoch is recorded.

---

### Plants are not growing well

| Symptom | Likely cause | Action |
|---|---|---|
| Pale or yellow leaves throughout | Insufficient light | Confirm the LED relay activates (watch the LED during 06:00–20:00 after day 2); check relay wiring |
| Yellow leaves only days 0–2 | Normal — germination blackout period | No action; lights activate from day 3 automatically |
| Wilting, very dry coir | Under-watering | Check pump runs (listen for motor); check moisture readings via `S`; increase `PUMP_RUN_SECONDS` in config.h |
| Mould (white fuzzy growth), soggy coir | Over-watering | Reduce `PUMP_RUN_SECONDS`; confirm skip threshold (70%) is working; increase spacing between seeds |
| Tall, spindly seedlings leaning toward door | LED too far from tray | Re-adjust LED bracket to 100mm above tray surface |
| Uneven germination (bare patches) | Uneven seed distribution or coir depth | Spread seeds more evenly; ensure coir depth is a consistent 2cm |
| Strong sulphur smell | Normal for broccoli family, strongest days 4–8 | Expected — not a problem; smell indicates healthy glucosinolate content |

---

### Device appears to have lost its schedule

**Symptom:** OLED shows all trays as `---` (empty), or the clock shows 2000-01-01.

**Cause:** Either the RTC clock lost power (dead coin cell or power was off for extended time), or the EEPROM tray data was reset (e.g. by a firmware re-flash that initialised the magic byte).

**Action:**
1. Set the clock if needed: `T<epoch>` in serial monitor.
2. If tray data is lost, you will need to reseed each tray manually. The device cannot recover previous grow-day counts if EEPROM was cleared. Start fresh with new seeds and press BOOT for each tray.
3. After any firmware re-flash, re-press BOOT for each active tray to re-register the cycles (the grow-day count restarts from 0, so harvest timing resets).

---

### Serial monitor shows no output or garbled text

**Cause:** Wrong baud rate (most common) or a charge-only USB cable.

**Action:** Set serial monitor to exactly **115200 baud**. Ensure your USB cable is data-capable — many phone charging cables carry power only. Try a different cable.

---

### Pump runs but moisture readings do not improve

**Possible causes:**
- Drip emitter blocked — water not reaching the tray
- Tubing kinked between manifold and tray level
- Moisture sensor calibration off (MOISTURE_DRY_RAW or MOISTURE_WET_RAW needs adjustment)
- Moisture sensor probe not fully inserted into coir

**Action:** Open the door during a pump run and watch whether water drips from the emitter into the tray. If no flow, clear the 2mm drip emitter orifice with a pin and check for kinked tubing. If flow is correct but readings do not change, recalibrate sensors per installation-guide.md Step 10.

---

### Pump does not run at scheduled times

**Symptom:** Expected watering events at 07:00 or 19:00 are not occurring.

**Possible causes:**
- All active trays are above the skip threshold (70% moisture) — this is normal and correct behaviour
- Pump relay not wired correctly
- Pump event for today already fired and was logged

**Action:** Type `S` in the serial monitor. Read the pump log section — it shows whether today's events have fired and the current moisture readings. If moisture is genuinely above 70%, no watering is needed and the skip is correct. If moisture is low but the pump did not run, check relay CH4 wiring and pump power connections.

---

## Configuration Reference

To change growing parameters, edit `software/firmware/microgreen_controller/config.h` and re-flash via Arduino IDE. See `docs/04-software/requirements.md` for full documentation of every parameter.

**Most commonly adjusted parameters:**

| Parameter | Default | What it controls |
|---|---|---|
| `PHOTO_ON_HOUR` | 6 | Hour when grow lights turn on (06:00) |
| `PHOTO_OFF_HOUR` | 20 | Hour when grow lights turn off (20:00) |
| `BLACKOUT_DAYS` | 2 | Days after seeding during which lights stay off |
| `WATER_HOUR_1` | 7 | Morning watering time (07:00) |
| `WATER_HOUR_2` | 19 | Evening watering time (19:00) |
| `GROW_DAYS` | 10 | Days after which a tray is available for reseeding |
| `HARVEST_DAY` | 8 | Day when harvest alert (red LED + beep) activates |
| `PUMP_RUN_SECONDS` | 90 | Pump run duration per event — calibrate to your pump |
| `MOISTURE_SKIP_THRESHOLD` | 70 | Skip watering if all trays read above this % |
| `MOISTURE_TOPUP_THRESHOLD` | 25 | Run extra pump if any tray reads below this % after main event |

---

## Quick Reference Card

**Normal daily operation:** Nothing required — device runs automatically.

**Refill water:** Unscrew reservoir lid (rear-left of base top) → pour up to 2 L → replace lid.

**Seed a tray:** Expand coir puck + soak seeds (4–8h) → spread coir in tray → spread seeds evenly → slide tray in → insert moisture sensor probe → press BOOT once → confirm 3 green LED flashes.

**Harvest:** Open door → slide growing tray out → cut greens ~5–10 mm above coir with clean scissors → use fresh, refrigerate up to 7 days, or freeze in 30 g portions.

**Clean and reseed:** Remove coir mat → rinse tray → empty sub-tray → air dry → reseed as above → press BOOT.

**Set clock:** USB to computer → Serial Monitor at 115200 baud → `T<unix_timestamp>` → Enter.

**Check status:** USB to computer → Serial Monitor at 115200 baud → `S` → Enter.

**Change settings:** Edit `config.h` in Arduino IDE → change value → Upload (re-flash).

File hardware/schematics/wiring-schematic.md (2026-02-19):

# Electrical Wiring Schematic — Microgreen Box

**Phase:** 03 Build (Electrical System)
**Status:** Complete
**Last Updated:** 2026-02-18
**Related decisions:** DECISION-008 through DECISION-019

---

## 1. Design Principles

| Principle | Implementation |
|---|---|
| Single primary voltage rail | 12V DC throughout |
| Voltage conversions | **Two stages only:** 12V→5V (MP1584 buck) then 5V→3.3V (ESP32 AMS1117 onboard) |
| All high-current 12V loads | Switched via relay, never through ESP32 |
| ESP32 3.3V GPIO protection | Relay module uses optocoupler isolation + JD-VCC separation |
| Reverse polarity | AO3401 P-channel MOSFET at input |
| Overcurrent | 5A inline blade fuse on 12V bus |
| Water safety | All signal wiring physically separated from water paths |

> **Why two conversion stages are unavoidable:** The ESP32 requires 3.3V logic. No commercially available 12V-native ESP32 dev board exists — all boards require 5V on VIN. Skipping the 12V→5V stage would require powering the ESP32's AMS1117 regulator directly from 12V, which exceeds its maximum input rating (8V abs. max for AMS1117-3.3). One buck stage is the minimum.

---

## 2. Power Flow Diagram

```
                         ┌─────────────────────────────────────────────┐
12V SOURCE               │              12V BUS                        │
(barrel jack             │                                             │
 5.5/2.1mm) ─────────► [AO3401]─►[5A Fuse]─────────────────────────►─┤
                         │                                             │
                         │  ┌──────────────────────────────────────┐  │
                         │  │      RELAY MODULE (4-ch)             │  │
                         │  │  CH1 COM──12V bus                    │  │
                         │  │  CH1 NO ─────────────────► LED A 12V │  │
                         │  │  CH2 NO ─────────────────► LED B 12V │  │
                         │  │  CH3 NO ─────────────────► LED C 12V │  │
                         │  │  CH4 NO ─────────────────► Pump 12V  │  │
                         │  │                                       │  │
                         │  │  JD-VCC ◄── 5V bus (coil power)      │  │
                         │  │  IN1–IN4 ◄── ESP32 GPIO (3.3V)       │  │
                         │  └──────────────────────────────────────┘  │
                         │                                             │
                         │  ┌──────────────────────────────────────┐  │
                         │  │  MP1584EN BUCK CONVERTER             │  │
                         │  │  IN: 12V   OUT: 5.00V (set/verified) │  │
                         │  └──────────────┬───────────────────────┘  │
                         │                 │ 5V BUS                    │
                         │        ┌────────┴──────────────┐            │
                         │        ▼                       ▼            │
                         │  [ESP32 VIN]           [Relay JD-VCC]       │
                         │  (AMS1117 onboard)     (coil supply)        │
                         │        │                                     │
                         │        ▼ 3.3V RAIL                          │
                         │  ┌──────────────────────────────────────┐  │
                         │  │  DS3231 RTC    SSD1306 OLED           │  │
                         │  │  Moisture ×3   Float switch pull-up   │  │
                         │  │  Status LEDs   Buzzer (via resistor)  │  │
                         │  └──────────────────────────────────────┘  │
                         └─────────────────────────────────────────────┘
```

---

## 3. Component List and Specifications

### 3.1 Power Input and Protection

| Ref | Component | Spec | Vendor / Part | URL | Price |
|-----|---|---|---|-----|---|
| J1 | DC barrel jack | 5.5/2.1mm panel-mount, positive tip | AliExpress | https://www.aliexpress.com/item/32828603866.html | ~$0.75 |
| F1 | Inline blade fuse + holder | 5A automotive blade, inline holder | Any hardware | — | ~$1.50 |
| Q1 | Reverse polarity protection | AO3401 P-ch MOSFET SOT-23; Gate to GND via 10kΩ, Source to 12V_in, Drain to fuse | AliExpress | — | ~$0.50 |
| U1 | Buck converter | MP1584EN module, 3A, adj. output — pre-set to 5.00V | AliExpress item 32828603866 | https://www.aliexpress.com/item/32828603866.html | ~$0.65 |

**Buck converter wiring:**
```
12V_BUS ──► MP1584 VIN+
GND     ──► MP1584 VIN−
MP1584 VOUT+ ──► 5V_BUS
MP1584 VOUT− ──► GND
```
> Pre-adjust output to exactly 5.00V with a multimeter before connecting any load. Turn trim pot clockwise to increase, counter-clockwise to decrease.

---

### 3.2 Microcontroller — ESP32-WROOM-32 (38-pin dev board)

| Ref | Component | Vendor / Part | URL | Price |
|-----|---|---|-----|---|
| U2 | ESP32-WROOM-32 38-pin | AliExpress item 32864722159 | https://www.aliexpress.com/item/32864722159.html | ~$1.83 |
| — | Amazon alt. (5-pack) | AITRIP B09DPH1KXF | https://www.amazon.com/dp/B09DPH1KXF | ~$2.60/board |

**Power connections:**
```
5V_BUS ──► ESP32 VIN   (onboard AMS1117 regulates to 3.3V)
GND    ──► ESP32 GND
```

**Do not connect 12V directly to VIN.** AMS1117-3.3 abs. max input: 15V but practical limit is 6V due to heat dissipation. Use the MP1584 5V rail.

---

### 3.3 GPIO Pin Assignments

| GPIO | Direction | Function | Connected to | Wire gauge |
|---|---|---|---|---|
| 13 | Output | Relay CH4 — Pump | Relay IN4 | 24 AWG |
| 16 | Output | Buzzer (optional) | Buzzer via 100Ω | 24 AWG |
| 17 | Output | Status LED — Tray B+C harvest (red) | LED via 330Ω | 24 AWG |
| 18 | Output | Status LED — Power on (green) | LED via 330Ω | 24 AWG |
| 19 | Output | Status LED — Water low (yellow) | LED via 330Ω | 24 AWG |
| 21 | I2C SDA | I2C data — RTC + OLED | DS3231 SDA, SSD1306 SDA | 24 AWG |
| 22 | I2C SCL | I2C clock — RTC + OLED | DS3231 SCL, SSD1306 SCL | 24 AWG |
| 25 | Output | Relay CH3 — LED Tray C (top ring) | Relay IN3 | 24 AWG |
| 26 | Output | Relay CH1 — LED Tray A (bottom ring) | Relay IN1 | 24 AWG |
| 27 | Output | Relay CH2 — LED Tray B (middle ring) | Relay IN2 | 24 AWG |
| 32 | ADC input | Moisture sensor C (ADC1_CH4) | Sensor C AOUT | 24 AWG |
| 33 | Digital input | Float switch — reservoir level | Float switch + 10kΩ pull-up | 24 AWG |
| 34 | ADC input | Moisture sensor A (ADC1_CH6, input-only) | Sensor A AOUT | 24 AWG |
| 35 | ADC input | Moisture sensor B (ADC1_CH7, input-only) | Sensor B AOUT | 24 AWG |
| 5  | Output | Status LED — Tray A harvest (red) | LED via 330Ω | 24 AWG |

**GPIO selection rationale:**
- GPIO34, 35: input-only pins (no internal pull-up/pull-down) — ideal for ADC; no conflict with output mode
- GPIO32, 33: full bidirectional with internal pull-up support; GPIO33 uses `INPUT_PULLUP` for float switch
- GPIO13, 25, 26, 27: safe output GPIOs (not strapping pins, not UART, not SPI flash)
- GPIO5: output-capable; note it is a strapping pin on some boards — verify it does not affect boot on your specific board
- GPIO16, 17, 18, 19: standard output GPIOs
- GPIO12 **avoided**: strapping pin affecting flash voltage on some modules
- GPIO0, 2, 15 **avoided**: boot-mode strapping pins
- GPIO6–11 **avoided**: connected to SPI flash
- GPIO1, 3 **avoided**: UART0 TX/RX (used for serial monitor / programming)
- ADC2 pins **avoided** for sensor input: ADC2 is disabled when WiFi is active (ESP-IDF limitation)

---

### 3.4 Real-Time Clock — DS3231

| Ref | Component | Vendor / Part | URL | Price |
|-----|---|---|-----|---|
| U3 | DS3231 + AT24C32 RTC module | AliExpress item 4000173986273 | https://www.aliexpress.com/item/4000173986273.html | ~$2.13 |

**Wiring:**
```
ESP32 3V3 ──► DS3231 VCC
ESP32 GND ──► DS3231 GND
ESP32 GPIO21 (SDA) ──► DS3231 SDA
ESP32 GPIO22 (SCL) ──► DS3231 SCL
```
CR2032 coin cell installed in module holder for backup timekeeping during power loss.
I2C address: 0x68 (DS3231), 0x57 (AT24C32 EEPROM — unused but shares bus).

---

### 3.5 OLED Display — SSD1306 (optional)

| Ref | Component | Vendor / Part | URL | Price |
|-----|---|---|-----|---|
| U4 | 0.96" 128×64 I2C OLED SSD1306 | AliExpress item 32643950109 | https://www.aliexpress.com/item/32643950109.html | ~$1.60 |

**Wiring (shared I2C bus with DS3231):**
```
ESP32 3V3 ──► OLED VCC
ESP32 GND ──► OLED GND
ESP32 GPIO21 (SDA) ──► OLED SDA
ESP32 GPIO22 (SCL) ──► OLED SCL
```
I2C address: 0x3C (verify with I2C scanner sketch if display doesn't appear).
I2C pull-up resistors (4.7kΩ to 3.3V) are typically included on the module boards.

---

### 3.6 Relay Module — 4-Channel

| Ref | Component | Vendor / Part | URL | Price |
|-----|---|---|-----|---|
| K1 | 4-ch 5V optocoupler relay module, hi/lo trigger | AliExpress item 32897567002 | https://www.aliexpress.com/item/32897567002.html | ~$3.10 |
| — | Amazon alt. | DIYables B0BXKKYH5C | https://www.amazon.com/dp/B0BXKKYH5C | ~$10 |

**Critical wiring note — JD-VCC isolation:**
```
5V_BUS ──► Relay JD-VCC   ← relay coil supply (DO NOT connect to ESP32 3.3V)
5V_BUS ──► Relay VCC      ← optocoupler logic supply  (OR leave floating if jumper removed)
GND    ──► Relay GND
```
**Remove the VCC–JD-VCC jumper** on the relay board. This electrically separates the relay coil power (5V, high inrush) from the optocoupler logic supply. Without this separation, relay coil switching causes voltage spikes on the 5V/3.3V lines that can reset the ESP32.

**Trigger mode:** Set to **LOW-level trigger** (jumper or solder bridge selection on board). ESP32 GPIO goes LOW to activate relay; HIGH (or floating with pull-up) to deactivate.

**Load wiring (all channels):**
```
12V_BUS ──► Relay CH[n] COM
Relay CH[n] NO ──► Load positive (LED V+ or Pump V+)
Load negative ──► GND
```

| Channel | Load | Peak current | Wire gauge |
|---|---|---|---|
| CH1 | LED strip — Tray A | 250–400 mA | 20 AWG |
| CH2 | LED strip — Tray B | 250–400 mA | 20 AWG |
| CH3 | LED strip — Tray C | 250–400 mA | 20 AWG |
| CH4 | Peristaltic pump | 400–800 mA | 20 AWG |

---

### 3.7 LED Grow Lighting

**Research basis:** Full-spectrum white (5000–6500K) or dedicated plant-spectrum strip. Target PPFD: 100 µmol/m²/s at tray surface (10 cm clearance). Research finding FINDING-009 confirms 100 µmol/m²/s balances sulforaphane, carotenoids, and vitamin C production optimally.

**Why not Samsung LM301H/LM281B boards:** All genuine Samsung quantum boards operate at 38–54V DC constant-current. They are incompatible with a 12V single-rail design without a 12V→48V boost converter — an additional conversion stage violating the single-rail design principle. Strip-based 12V panels are the correct choice for this constraint.

| Ref | Component | Vendor / Part | URL | Price |
|-----|---|---|-----|---|
| LED1–3 | **Primary:** 12V full-spectrum plant grow strip (red+blue+white, 5050) | AliExpress item 32816538353 | https://www.aliexpress.com/item/32816538353.html | ~$11.41 (covers all 3 trays) |
| LED1–3 | **Alt (white spectrum):** Tesfish 12V 2835 6000K 240LED/m 5m roll | Amazon B08T89VRPP | https://www.amazon.com/dp/B08T89VRPP | ~$10 (covers all 3 trays) |

**Panel construction (DIY, per tray):**
1. Cut strip to **3× 60cm lengths** (4× 15cm sub-lengths per panel in zigzag) from one roll
2. Mount in zigzag pattern on 3D-printed `led_panel.stl` sled (100×100mm)
3. Back sled with aluminium tape for passive heat sinking
4. Seal strip with clear conformal coating (acrylic spray) for humidity protection
5. Terminate with JST-XH 2-pin connector (male, 20AWG leads) to relay NO/GND

**Power per panel (60cm of 5050 strip at 12V):**
```
5050 strip: ~60 LED/m × 0.15–0.25W/LED = ~9–15W/m
60cm strip: ~5.4–9W per panel

→ Exceeds 3W target. To limit to 3W, use a 10Ω 5W series resistor per panel.
  At 250mA draw: V_drop = 0.25A × 10Ω = 2.5V; power in resistor = 0.625W (safe)

Alternative: Use a shorter cut (25cm of 5050 strip) ≈ 3.75W ≈ within target.
```

**For the 2835 alternative (Tesfish 240LED/m):**
```
240LED/m at 12V ≈ 14.4W/m (typical for 2835 high density)
25cm cut ≈ 3.6W → close to 3W target, no resistor needed
Arrange: 1× 25cm strip folded in tight U-shape on 100×100mm sled
```

**LED wiring per channel:**
```
Relay CH[n] NO ──► 20AWG red ──► [Series resistor 10Ω 5W if using 60cm] ──► Strip V+
Strip V− ──► 20AWG black ──► GND
```

---

### 3.8 Peristaltic Pump

| Ref | Component | Vendor / Part | URL | Price |
|-----|---|---|-----|---|
| M1 | **Primary:** INTLLAB 12V peristaltic pump, 5–100 mL/min, 4-pack | Amazon B088TBKNSY | https://www.amazon.com/dp/B088TBKNSY | ~$25.80/4pk (~$6.45 each; buy 1 pack, keep 3 spare) |
| M1 | **Alt (adjustable):** Gikfun EK1971, 8–70 mL/min, with tubing | Amazon B0B4FMSJPV | https://www.amazon.com/dp/B0B4FMSJPV | ~$15–20 |
| M1 | **Alt (AliExpress):** R385 motor peristaltic head, 12V | AliExpress item 32770860268 | https://www.aliexpress.com/i/32770860268.html | ~$4–8 |

**Flow rate target:** 25 mL per tray per event × 3 trays = 75 mL per pump run.
At 50 mL/min, run time per event = 90 seconds. At 100 mL/min, 45 seconds.
> Set `pump_run_seconds` in firmware accordingly after measuring actual flow rate.

**Wiring:**
```
Relay CH4 NO ──► 20AWG red  ──► Pump V+ (red wire)
GND          ──► 20AWG black ──► Pump V− (black wire)
```
Pump polarity: red = positive. Reversing polarity reverses pumping direction — ensure correct orientation.
Tubing: 3mm ID × 5mm OD food-grade silicone (typically included with pump).

---

### 3.9 Coir Moisture Sensors (×3, one per tray)

**Design role:** Analog feedback for watering control. Supplements timer-based scheduling. If sensor reads "dry" after a scheduled event, firmware can trigger a short top-up cycle. If it reads "saturated" before a scheduled event, firmware skips that event.

| Ref | Component | Vendor / Part | URL | Price |
|-----|---|---|-----|---|
| S1–S3 | Capacitive Soil Moisture Sensor V1.2 | AliExpress item 32853373769 | https://www.aliexpress.com/item/32853373769.html | ~$1.22 each |
| S1–S3 | Amazon alt. (2-pack) | Gikfun EK1940 B07H3P1NRM | https://www.amazon.com/dp/B07H3P1NRM | ~$8–10/2pk |

**Wiring (identical for all three sensors):**
```
ESP32 3V3  ──► Sensor VCC
ESP32 GND  ──► Sensor GND
Sensor AOUT ──► ESP32 GPIO34 (Sensor A, Tray A — bottom)
Sensor AOUT ──► ESP32 GPIO35 (Sensor B, Tray B — middle)
Sensor AOUT ──► ESP32 GPIO32 (Sensor C, Tray C — top)
```

**Analog output behaviour (3.3V powered):**
- Dry coir (0% moisture): ~2.8–3.0V output
- Moist coir (field capacity, ~50%): ~1.5–1.8V output
- Saturated: ~0.8–1.2V output

**Calibration procedure (required on first use):**
1. Read raw ADC value with sensor in dry air → record as `DRY_THRESHOLD`
2. Read raw ADC value with sensor fully submerged in water → record as `WET_THRESHOLD`
3. `moisture_percent = map(adc_reading, DRY_THRESHOLD, WET_THRESHOLD, 0, 100)`
4. Firmware uses `moisture_percent < 30` as "needs water" flag; `moisture_percent > 70` as "skip watering"

**Physical installation:** Insert sensor vertically into coir to approximately half sensor depth (~3–4cm). Route cable through the rear wall drip port or a dedicated small cable grommet. Conformal-coat the sensor body (not the sensing tip) to protect from humidity.

---

### 3.10 Reservoir Float Switch

**Design role:** Binary low-water alarm. Provides definitive HIGH/LOW signal without calibration. Replaces the XKC-Y25-V capacitive approach (which requires precise flush mounting on PETG exterior — difficult in practice).

| Ref | Component | Vendor / Part | URL | Price |
|-----|---|---|-----|---|
| SW1 | ZP2508 mini vertical float switch, NC (normally closed) | AliExpress item 4000246458661 | https://www.aliexpress.com/item/4000246458661.html | ~$0.62 |

**Specs:** Body 19mm × 36mm total height, PP float, reed switch internal, max 0.5A switching, −10 to +85°C, 2-wire passive.

**Normally closed (NC) behaviour:**
- Float DOWN (water LOW): NC contacts **closed** → GPIO reads LOW (alarm condition)
- Float UP (water ADEQUATE): NC contacts **open** → GPIO reads HIGH (normal)

**Wiring:**
```
ESP32 3V3 ──► 10kΩ resistor ──┬──► ESP32 GPIO33 (input, INPUT_PULLUP mode)
                               │
                          Float switch
                          (NC contact)
                               │
                             GND
```
> In `INPUT_PULLUP` mode the ESP32 provides an internal ~45kΩ pull-up. The external 10kΩ adds a stronger pull-up. LOW = water low = trigger alert.

**Physical installation:** The float switch mounts inside the reservoir through a Ø5mm hole drilled or printed into the reservoir lid (reservoir_lid.stl). Use a rubber cable gland (M5 size, ~$0.30 each) to waterproof the wire entry. Suspend the switch body by its cable, positioned at the desired low-water threshold height (~20mm above reservoir floor). The float must hang freely without touching reservoir walls.

**Reservoir lid modification:** The current reservoir_lid.stl design has no cable gland port. Either:
- Drill a 5mm hole in a printed lid and install a rubber cable gland, or
- Add the port to the OpenSCAD source (`reservoir_lid.scad` — `lid_h` section) for next print

---

### 3.11 Status Indicators

**Wiring (all from 3.3V GPIO via current-limiting resistors):**
```
GPIO18 ──► 330Ω ──► Green LED anode ──► LED cathode ──► GND   [Power on]
GPIO19 ──► 330Ω ──► Yellow LED anode ──► LED cathode ──► GND  [Water low]
GPIO5  ──► 330Ω ──► Red LED anode ──► LED cathode ──► GND     [Tray A harvest]
GPIO17 ──► 330Ω ──► Red LED anode ──► LED cathode ──► GND     [Tray B+C harvest]
GPIO16 ──► 100Ω ──► Active buzzer + ──► Buzzer − ──► GND      [Audio alert, optional]
```
LED current: (3.3V − 2.0V) / 330Ω ≈ 4mA per LED — well within ESP32 12mA GPIO limit.
All four LEDs on simultaneously: 4 × 4mA = 16mA total — within ESP32 total output current limits.

---

### 3.12 Ventilation Fan — 40mm 12V Brushless Fan with Manual Switch (DECISION-024)

**Purpose:** Active humidity management. User-controlled — no relay, no firmware involvement. Run the fan when surface mould is observed, humidity is persistently high, or during warm-weather operation.

| Ref | Component | Vendor / Part | URL | Price |
|-----|---|---|-----|---|
| FAN1 | 40mm 12V brushless fan, 40×40×10mm, ≤25 dBA | AliExpress / Amazon | — | ~$3.00 |
| SW2 | SPST mini toggle switch, panel-mount, 6mm body, 12V rated | AliExpress / Electronics shop | — | ~$1.00 |
| GRD1 | 40mm fan guard/grill, snap-fit | AliExpress | — | ~$0.50 |

**Circuit (manual, hardware-only):**
```
12V_BUS ──► SW2 (toggle switch — top cap front face) ──► FAN1 red (+) wire
FAN1 black (−) wire ──► GND
```

**Physical installation:**
- Fan mounted on top cap top surface; fan body sits in 42mm recess; label/inlet side faces INTO the cap; exhaust goes upward
- Fan secured with 4× M3×12mm bolts through fan corners into 4× M3 hex nuts (fan_bolt_ctc = 32mm square pattern)
- Fan guard snaps onto the fan exterior (top-facing) surface
- Toggle switch mounted in 6.5mm panel-cut hole on top cap front face, X=255mm, Z=50mm (right side, clear of OLED and status LEDs)
- Power tap: 20AWG wire from 12V bus at stripboard → SW2 input → SW2 output → FAN1 red (+) → FAN1 black (−) → GND bus

**Passive intake path:** Existing ring vent slots (25×8mm slide-cover slots at the top of each ring's front and rear walls) allow ambient air in from the lower rings when slide covers are removed. Airflow: intake through lower ring vent slots → up through column interior → exhaust via top cap fan.

**Electrical specs:**
- Typical 40mm 12V brushless fan: 0.08–0.15A at 12V = ~1–1.8W
- No relay required (toggle switch rated for 12V DC directly)
- Negligible impact on power budget: <2W peak, zero when off
- No firmware changes required — completely independent hardware circuit

---

## 4. Complete Wire-by-Wire Connection Table

| From | From pin/terminal | To | To pin/terminal | Wire | Colour |
|---|---|----|---|---|---|
| J1 (barrel jack) | + tip | Q1 (AO3401 Source) | S | 20 AWG | Red |
| J1 (barrel jack) | − sleeve | GND bus | — | 20 AWG | Black |
| Q1 (AO3401 Drain) | D | F1 (fuse holder) | in | 20 AWG | Red |
| F1 (fuse holder) | out | 12V bus | — | 20 AWG | Red |
| 12V bus | — | U1 (MP1584) | VIN+ | 20 AWG | Red |
| GND bus | — | U1 (MP1584) | VIN− | 20 AWG | Black |
| U1 (MP1584) | VOUT+ | 5V bus | — | 20 AWG | Orange |
| U1 (MP1584) | VOUT− | GND bus | — | 20 AWG | Black |
| 5V bus | — | U2 (ESP32) | VIN | 24 AWG | Orange |
| GND bus | — | U2 (ESP32) | GND | 24 AWG | Black |
| 5V bus | — | K1 (relay) | JD-VCC | 24 AWG | Orange |
| 5V bus | — | K1 (relay) | VCC | 24 AWG | Orange |
| GND bus | — | K1 (relay) | GND | 24 AWG | Black |
| U2 GPIO26 | — | K1 (relay) | IN1 | 24 AWG | Yellow |
| U2 GPIO27 | — | K1 (relay) | IN2 | 24 AWG | Yellow |
| U2 GPIO25 | — | K1 (relay) | IN3 | 24 AWG | Yellow |
| U2 GPIO13 | — | K1 (relay) | IN4 | 24 AWG | Yellow |
| 12V bus | — | K1 (relay) CH1 | COM | 20 AWG | Red |
| 12V bus | — | K1 (relay) CH2 | COM | 20 AWG | Red |
| 12V bus | — | K1 (relay) CH3 | COM | 20 AWG | Red |
| 12V bus | — | K1 (relay) CH4 | COM | 20 AWG | Red |
| K1 CH1 | NO | LED strip A | V+ | 20 AWG | Red |
| K1 CH2 | NO | LED strip B | V+ | 20 AWG | Red |
| K1 CH3 | NO | LED strip C | V+ | 20 AWG | Red |
| K1 CH4 | NO | M1 (pump) | V+ | 20 AWG | Red |
| LED strip A | V− | GND bus | — | 20 AWG | Black |
| LED strip B | V− | GND bus | — | 20 AWG | Black |
| LED strip C | V− | GND bus | — | 20 AWG | Black |
| M1 (pump) | V− | GND bus | — | 20 AWG | Black |
| ESP32 3V3 | — | U3 (DS3231) | VCC | 24 AWG | Purple |
| GND bus | — | U3 (DS3231) | GND | 24 AWG | Black |
| U2 GPIO21 | SDA | U3 (DS3231) | SDA | 24 AWG | Blue |
| U2 GPIO22 | SCL | U3 (DS3231) | SCL | 24 AWG | Green |
| ESP32 3V3 | — | U4 (OLED) | VCC | 24 AWG | Purple |
| GND bus | — | U4 (OLED) | GND | 24 AWG | Black |
| U2 GPIO21 | SDA | U4 (OLED) | SDA | 24 AWG | Blue |
| U2 GPIO22 | SCL | U4 (OLED) | SCL | 24 AWG | Green |
| ESP32 3V3 | — | S1 (moist. A) | VCC | 24 AWG | Purple |
| ESP32 3V3 | — | S2 (moist. B) | VCC | 24 AWG | Purple |
| ESP32 3V3 | — | S3 (moist. C) | VCC | 24 AWG | Purple |
| GND bus | — | S1 (moist. A) | GND | 24 AWG | Black |
| GND bus | — | S2 (moist. B) | GND | 24 AWG | Black |
| GND bus | — | S3 (moist. C) | GND | 24 AWG | Black |
| S1 | AOUT | U2 GPIO34 | ADC | 24 AWG | White |
| S2 | AOUT | U2 GPIO35 | ADC | 24 AWG | White |
| S3 | AOUT | U2 GPIO32 | ADC | 24 AWG | White |
| ESP32 3V3 | — | 10kΩ resistor | one end | 24 AWG | Purple |
| 10kΩ resistor | other end | U2 GPIO33 | digital in | 24 AWG | White |
| 10kΩ resistor | other end | SW1 (float) | wire 1 | 24 AWG | White |
| SW1 (float) | wire 2 | GND bus | — | 24 AWG | Black |
| U2 GPIO18 | — | 330Ω | — | 24 AWG | — |
| 330Ω | — | Green LED anode | — | 24 AWG | Green |
| Green LED cathode | — | GND bus | — | 24 AWG | Black |
| U2 GPIO19 | — | 330Ω | — | 24 AWG | — |
| 330Ω | — | Yellow LED anode | — | 24 AWG | Yellow |
| Yellow LED cathode | — | GND bus | — | 24 AWG | Black |
| U2 GPIO5 | — | 330Ω | — | 24 AWG | — |
| 330Ω | — | Red LED A anode | — | 24 AWG | Red |
| Red LED A cathode | — | GND bus | — | 24 AWG | Black |
| U2 GPIO17 | — | 330Ω | — | 24 AWG | — |
| 330Ω | — | Red LED B anode | — | 24 AWG | Red |
| Red LED B cathode | — | GND bus | — | 24 AWG | Black |
| U2 GPIO16 | — | 100Ω | — | 24 AWG | — |
| 100Ω | — | Buzzer + | — | 24 AWG | — |
| Buzzer − | — | GND bus | — | 24 AWG | Black |

---

## 5. Power Budget

| Load | Voltage | Typical current | Typical power | Duty cycle | Avg power |
|---|---|---|---|---|---|
| LED strip A | 12V | 250–500 mA | 3–6W | 14/24h | 1.75–3.5W |
| LED strip B | 12V | 250–500 mA | 3–6W | 14/24h | 1.75–3.5W |
| LED strip C | 12V | 250–500 mA | 3–6W | 14/24h | 1.75–3.5W |
| Pump | 12V | 300–700 mA | 3.6–8.4W | ~3min/day | ~0.03W |
| Relay coils (all 4) | 5V | 4× 60–80 mA = 240–320 mA | 1.2–1.6W | always | 1.2–1.6W |
| ESP32 (active) | 5V | 80–240 mA | 0.4–1.2W | always | 0.5W |
| DS3231 RTC | 3.3V | 1.5 mA | 0.005W | always | 0.005W |
| SSD1306 OLED | 3.3V | 10–20 mA | 0.05W | always | 0.05W |
| 3× moisture sensors | 3.3V | 3× 5 mA | 0.05W | ~5min/hr | 0.004W |
| Status LEDs (worst case all on) | 3.3V | 4× 4 mA | 0.05W | varies | ~0.02W |
| Ventilation fan (when on) | 12V | 80–150 mA | 1–1.8W | manual | varies |
| **Peak power (all LEDs + pump)** | 12V in | **~1.25A** | **~15W** | — | — |
| **Average power (LEDs 14h/day)** | 12V in | **~0.55A** | **~6.6W** | — | — |
| **Peak with fan running** | 12V in | **~1.40A** | **~16.8W** | — | — |

**5A fuse at 12V = 60W capacity.** Peak of 15W is well within fuse rating.
**40W solar panel** at 4 peak-sun-hours × 0.85 efficiency = 136 Wh/day vs 6.6W × 24h = 158 Wh/day → marginal. Consider 50W panel for comfortable solar margin.

---

## 6. Connector Map

All inter-module connections use JST-XH 2.54mm connectors for quick-disconnect service. Wire colours follow automotive convention (red=+12V, orange=+5V, purple=+3.3V, black=GND, yellow=signal, blue=SDA, green=SCL, white=analog, grey=misc signal).

| Connector | Pins | Location | Connected to |
|---|---|---|---|
| J2 | 2-pin XH | Base electronics bay | LED strip A (ring 1) |
| J3 | 2-pin XH | Base electronics bay | LED strip B (ring 2) |
| J4 | 2-pin XH | Base electronics bay | LED strip C (ring 3) |
| J5 | 2-pin XH | Base electronics bay | Pump |
| J6 | 3-pin XH | Base electronics bay | Moisture sensor A (Tray A) |
| J7 | 3-pin XH | Base electronics bay | Moisture sensor B (Tray B) |
| J8 | 3-pin XH | Base electronics bay | Moisture sensor C (Tray C) |
| J9 | 2-pin XH | Reservoir lid port | Float switch SW1 |
| J10 | 4-pin XH | Top cap | OLED display |
| J11 | 2-pin XH | Base / top cap | 12V power in from barrel jack |

---

## 7. Safety and Verification Checklist

Perform these checks in order before first power-on:

- [ ] Buck converter output verified at 5.00V DC (multimeter on VOUT terminals, no load)
- [ ] Relay JD-VCC jumper removed (optocoupler supply isolated from coil supply)
- [ ] All JST-XH connectors fully seated (audible click)
- [ ] Polarity verified on pump, LED strips (red = positive)
- [ ] Float switch cable gland in reservoir lid fully tightened (watertight)
- [ ] 5A fuse installed in F1 holder
- [ ] No 12V wiring near water paths (reservoir, sub-trays, drain tubing)
- [ ] ESP32 not yet connected when adjusting buck converter output
- [ ] I2C bus scan performed after first boot (confirms DS3231 at 0x68, OLED at 0x3C)
- [ ] Relay channels tested individually via serial console before enabling schedule
- [ ] Moisture sensors calibrated (dry air → submerged water readings recorded)
- [ ] Float switch LOW/HIGH state confirmed: pull float down → GPIO33 LOW; release → HIGH

---
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

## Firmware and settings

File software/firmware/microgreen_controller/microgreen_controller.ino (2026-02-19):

// =============================================================================
// microgreen_controller.ino — Microgreen Box Firmware v1.0
// =============================================================================
// Hardware  : ESP32-WROOM-32 (38-pin dev board)
// Framework : Arduino (ESP32 Arduino Core)
//
// What this firmware does:
//   - Controls grow-light LEDs per tray on a 14 h/10 h photoperiod
//   - Enforces germination blackout (lights off days 0–2) per tray
//   - Runs peristaltic pump on a timed schedule (morning + evening)
//   - Reads capacitive moisture sensors; skips watering if coir is wet,
//     adds a top-up pass if coir stays dry after pumping
//   - Monitors reservoir float switch; sounds alarm when water is low
//   - Maintains a grow-day counter per tray across power cycles (EEPROM)
//   - Activates harvest LED + buzzer when a tray reaches harvest day
//   - Displays live status on 128×64 SSD1306 OLED (optional — works without)
//   - Blinks green LED as heartbeat; fast blink when any alarm is active
//   - Light-sleeps between 60-second check cycles to conserve power
//   - Single button (GPIO0/BOOT) seeds the next available tray
//
// Library dependencies (install via Arduino IDE → Manage Libraries):
//   RTClib           by Adafruit
//   Adafruit GFX     by Adafruit
//   Adafruit SSD1306 by Adafruit
//
// Serial commands (115200 baud, newline-terminated):
//   T<epoch>   Set RTC to Unix timestamp, e.g. "T1739836800"
//   S          Print full status dump
// =============================================================================

#include "config.h"
#include <Wire.h>
#include <EEPROM.h>
#include <RTClib.h>
#include <Adafruit_GFX.h>
#include <Adafruit_SSD1306.h>
#include "esp_sleep.h"
#include "driver/gpio.h"

// =============================================================================
// Hardware objects
// =============================================================================

RTC_DS3231       rtc;
Adafruit_SSD1306 oled(128, 64, &Wire, -1);

bool rtc_ok  = false;
bool oled_ok = false;

// =============================================================================
// Tray state
// =============================================================================

struct Tray {
    uint32_t seed_epoch;   // Unix timestamp when tray was seeded; 0 = empty
    int8_t   day;          // Current grow day (0 = seeded today; -1 = empty)
    uint8_t  moisture;     // Last moisture reading 0–100 %
    bool     light_on;     // Whether this tray's relay is currently energised
};

Tray trays[3];   // [0] = Tray A (bottom ring), [1] = B (middle), [2] = C (top)

// Parallel arrays matching tray index → GPIO pin
static const uint8_t RELAY_PINS[3]    = { PIN_RELAY_LED_A, PIN_RELAY_LED_B, PIN_RELAY_LED_C };
static const uint8_t MOISTURE_PINS[3] = { PIN_MOISTURE_A,  PIN_MOISTURE_B,  PIN_MOISTURE_C  };

// =============================================================================
// Pump log — tracks which daily watering events have already fired
// =============================================================================

struct PumpLog {
    uint16_t day_number;    // Days-since-epoch value on which events were recorded
    bool     event1_done;   // Morning event has fired today
    bool     event2_done;   // Evening event has fired today
};

PumpLog pump_log;

// =============================================================================
// Runtime state
// =============================================================================

bool pump_running     = false;
bool water_low_alarm  = false;
bool prev_water_low   = false;            // Previous state for transition detection
bool harvest_beeped[3] = {false, false, false};  // One-shot harvest alert per tray

// Button interrupt flag
volatile bool          button_event = false;
volatile unsigned long btn_press_ms = 0;

// Heartbeat (non-blocking, millis-based)
unsigned long heartbeat_ms = 0;
bool          heartbeat_hi = false;

// =============================================================================
// EEPROM layout (32 bytes total)
//   Addr  0      : magic byte (0xA5 = data valid)
//   Addr  1–4    : Tray A seed_epoch (uint32, little-endian)
//   Addr  5–8    : Tray B seed_epoch
//   Addr  9–12   : Tray C seed_epoch
//   Addr 13–14   : pump_log.day_number (uint16, little-endian)
//   Addr 15      : pump_log flags  bit0=event1_done  bit1=event2_done
//   Addr 16–31   : reserved
// =============================================================================

#define EEPROM_SIZE        32
#define EEPROM_MAGIC_ADDR   0
#define EEPROM_TRAY_BASE    1    // 3 × 4 bytes = addresses 1–12
#define EEPROM_PUMP_BASE   13    // 3 bytes
#define EEPROM_MAGIC_VAL  0xA5

static void eeprom_write32(int addr, uint32_t v) {
    EEPROM.write(addr,     (uint8_t)(v       & 0xFF));
    EEPROM.write(addr + 1, (uint8_t)(v >>  8 & 0xFF));
    EEPROM.write(addr + 2, (uint8_t)(v >> 16 & 0xFF));
    EEPROM.write(addr + 3, (uint8_t)(v >> 24 & 0xFF));
}

static uint32_t eeprom_read32(int addr) {
    return (uint32_t)EEPROM.read(addr)
         | ((uint32_t)EEPROM.read(addr + 1) <<  8)
         | ((uint32_t)EEPROM.read(addr + 2) << 16)
         | ((uint32_t)EEPROM.read(addr + 3) << 24);
}

static void save_state() {
    for (int i = 0; i < 3; i++)
        eeprom_write32(EEPROM_TRAY_BASE + i * 4, trays[i].seed_epoch);

    EEPROM.write(EEPROM_PUMP_BASE,
                 (uint8_t)(pump_log.day_number & 0xFF));
    EEPROM.write(EEPROM_PUMP_BASE + 1,
                 (uint8_t)((pump_log.day_number >> 8) & 0xFF));
    EEPROM.write(EEPROM_PUMP_BASE + 2,
                 (uint8_t)((pump_log.event1_done ? 1 : 0) |
                            (pump_log.event2_done ? 2 : 0)));
    EEPROM.commit();
}

static void load_state() {
    EEPROM.begin(EEPROM_SIZE);

    if (EEPROM.read(EEPROM_MAGIC_ADDR) != EEPROM_MAGIC_VAL) {
        // First boot: initialise to default (all trays empty)
        for (int i = 0; i < 3; i++) trays[i].seed_epoch = 0;
        pump_log = { 0, false, false };
        EEPROM.write(EEPROM_MAGIC_ADDR, EEPROM_MAGIC_VAL);
        save_state();
        Serial.println("EEPROM: first boot — defaults written");
    } else {
        for (int i = 0; i < 3; i++)
            trays[i].seed_epoch = eeprom_read32(EEPROM_TRAY_BASE + i * 4);

        uint16_t dn = (uint16_t)EEPROM.read(EEPROM_PUMP_BASE)
                    | ((uint16_t)EEPROM.read(EEPROM_PUMP_BASE + 1) << 8);
        uint8_t  fl = EEPROM.read(EEPROM_PUMP_BASE + 2);
        pump_log = { dn, bool(fl & 1), bool(fl & 2) };
        Serial.println("EEPROM: tray state restored");
    }
}

// =============================================================================
// Relay helpers
// LOW-level trigger module: LOW = relay energised = load ON
// =============================================================================

static inline void relay_on (uint8_t pin) { digitalWrite(pin, LOW);  }
static inline void relay_off(uint8_t pin) { digitalWrite(pin, HIGH); }

// =============================================================================
// Grow day calculation
// Returns -1 for empty tray, or 0..127 for active tray.
// =============================================================================

static int8_t compute_day(uint32_t seed_epoch, uint32_t now_epoch) {
    if (seed_epoch == 0 || now_epoch < seed_epoch) return -1;
    int32_t days = (int32_t)((now_epoch - seed_epoch) / 86400UL);
    return (int8_t)min(days, (int32_t)127);
}

// =============================================================================
// Moisture sensor reading
// ADC1, 12-bit (0–4095), 3.3 V reference.
// Capacitive V1.2: dry air = high counts, saturated = low counts.
// Averages 8 samples to reduce ADC noise. Returns 0–100 %.
// =============================================================================

static uint8_t read_moisture(uint8_t pin) {
    int32_t sum = 0;
    for (int i = 0; i < 8; i++) {
        sum += analogRead(pin);
        delayMicroseconds(500);
    }
    int raw = (int)(sum / 8);
    int pct = map(raw, MOISTURE_DRY_RAW, MOISTURE_WET_RAW, 0, 100);
    return (uint8_t)constrain(pct, 0, 100);
}

// =============================================================================
// Float switch
// NC contact. Float down (water LOW) → contacts closed → GPIO pulled LOW → alarm.
// Float up  (water OK)  → contacts open  → GPIO pulled HIGH by INPUT_PULLUP.
// =============================================================================

static bool water_is_low() {
    return digitalRead(PIN_FLOAT_SWITCH) == LOW;
}

// =============================================================================
// Button ISR — debounced falling edge on GPIO0 (active-low)
// =============================================================================

void IRAM_ATTR on_button_isr() {
    unsigned long t = millis();
    if (t - btn_press_ms > BUTTON_DEBOUNCE_MS) {
        button_event = true;
        btn_press_ms = t;
    }
}

// =============================================================================
// Seed the next available tray
// Available = seed_epoch == 0 (never used) OR day >= GROW_DAYS (cycle complete).
// Searches trays in order A → B → C. If all are active, flashes red.
// =============================================================================

static void seed_next_tray(uint32_t now_epoch) {
    for (int i = 0; i < 3; i++) {
        if (trays[i].seed_epoch == 0 || trays[i].day >= GROW_DAYS) {
            trays[i].seed_epoch = now_epoch;
            trays[i].day        = 0;
            harvest_beeped[i]   = false;
            save_state();
            Serial.printf("Tray %c seeded at epoch %lu (day 0)\n",
                          'A' + i, (unsigned long)now_epoch);
            // Three quick green flashes to confirm
            for (int f = 0; f < 3; f++) {
                digitalWrite(PIN_LED_GREEN, HIGH); delay(80);
                digitalWrite(PIN_LED_GREEN, LOW);  delay(80);
            }
            return;
        }
    }
    // No tray available — five quick red flashes
    Serial.println("Button: no tray available to seed (all active)");
    for (int f = 0; f < 5; f++) {
        digitalWrite(PIN_LED_RED_A, HIGH); delay(60);
        digitalWrite(PIN_LED_RED_A, LOW);  delay(60);
    }
}

// =============================================================================
// Run the pump
//
// Pre-run:  if skip_check is false, evaluate moisture only for ESTABLISHED
//           trays (day > GERMINATION_WATER_DAYS). Germinating trays are
//           excluded from the skip/topup decisions — seeds were just soaked
//           and over-watering days 0–GERMINATION_WATER_DAYS is the primary
//           cause of damping-off (Pythium). Germinating trays still receive
//           water when established trays trigger a run; they just cannot
//           trigger runs themselves.
//           Skip if: no established trays exist, OR all established trays
//           read >= MOISTURE_SKIP_THRESHOLD.
// Main run: pump runs for PUMP_RUN_SECONDS.
// Post-run: wait MOISTURE_SETTLE_SECONDS, re-read moisture for all active
//           trays; trigger top-up only if any ESTABLISHED tray still reads
//           below MOISTURE_TOPUP_THRESHOLD.
// =============================================================================

static void run_pump(bool skip_check) {
    if (!skip_check) {
        // Only established trays (past germination window) drive watering decisions.
        bool any_established = false;
        bool any_dry         = false;
        for (int i = 0; i < 3; i++) {
            if (trays[i].day > GERMINATION_WATER_DAYS) {
                any_established = true;
                if (trays[i].moisture < MOISTURE_SKIP_THRESHOLD)
                    any_dry = true;
            }
        }
        if (!any_established) {
            Serial.println("Pump: skipped — all active trays in germination period");
            return;
        }
        if (!any_dry) {
            Serial.println("Pump: skipped — all established trays are adequately moist");
            return;
        }
    }

    // Main pump run
    Serial.printf("Pump: ON (%d s)\n", PUMP_RUN_SECONDS);
    pump_running = true;
    relay_on(PIN_RELAY_PUMP);
    delay((unsigned long)PUMP_RUN_SECONDS * 1000UL);
    relay_off(PIN_RELAY_PUMP);
    pump_running = false;
    Serial.println("Pump: OFF");

    // Allow coir to absorb water before re-reading
    Serial.printf("Pump: settling %d s...\n", MOISTURE_SETTLE_SECONDS);
    delay((unsigned long)MOISTURE_SETTLE_SECONDS * 1000UL);

    // Re-read all active trays for display; top-up only for established trays.
    bool needs_topup = false;
    for (int i = 0; i < 3; i++) {
        if (trays[i].day >= 0) {
            trays[i].moisture = read_moisture(MOISTURE_PINS[i]);
            if (trays[i].day > GERMINATION_WATER_DAYS &&
                trays[i].moisture < MOISTURE_TOPUP_THRESHOLD)
                needs_topup = true;
        }
    }

    if (needs_topup) {
        Serial.printf("Pump: top-up (%d s)\n", PUMP_TOPUP_SECONDS);
        pump_running = true;
        relay_on(PIN_RELAY_PUMP);
        delay((unsigned long)PUMP_TOPUP_SECONDS * 1000UL);
        relay_off(PIN_RELAY_PUMP);
        pump_running = false;
        Serial.println("Pump: top-up OFF");
    }
}

// =============================================================================
// Light schedule
// Each tray's relay is set independently based on its grow day and the hour.
// Relay state is only changed when it needs to change (avoids relay chatter).
// =============================================================================

static void apply_lights(int hour) {
    bool photoperiod_active = (hour >= PHOTO_ON_HOUR && hour < PHOTO_OFF_HOUR);

    for (int i = 0; i < 3; i++) {
        // Light is ON only when: tray is past blackout days AND in photoperiod
        bool want_on = (trays[i].day > BLACKOUT_DAYS) && photoperiod_active;

        if (want_on != trays[i].light_on) {
            if (want_on) relay_on(RELAY_PINS[i]);
            else         relay_off(RELAY_PINS[i]);
            trays[i].light_on = want_on;
            Serial.printf("Light %c: %s\n", 'A' + i, want_on ? "ON" : "OFF");
        }
    }
}

// =============================================================================
// Watering schedule
// Resets the daily pump log when the day-number changes (midnight rollover).
// Fires each event once per day at the configured hour.
// =============================================================================

static void apply_watering(int hour, uint16_t today) {
    // New day: reset event flags
    if (pump_log.day_number != today) {
        pump_log = { today, false, false };
        save_state();
    }

    if (hour == WATER_HOUR_1 && !pump_log.event1_done) {
        pump_log.event1_done = true;
        save_state();
        Serial.println("Watering: event 1 (morning)");
        run_pump(false);

    } else if (hour == WATER_HOUR_2 && !pump_log.event2_done) {
        pump_log.event2_done = true;
        save_state();
        Serial.println("Watering: event 2 (evening)");
        run_pump(false);
    }
}

// =============================================================================
// Status indicators
// Yellow LED tracks water alarm state every loop.
// Red LEDs track harvest-ready state every loop.
// Buzzer: two beeps on water-low rising edge; one beep on first harvest event.
// =============================================================================

static void update_indicators() {
    // Yellow: water low
    digitalWrite(PIN_LED_YELLOW, water_low_alarm ? HIGH : LOW);

    // Red A: Tray A harvest ready
    bool ha = (trays[0].day >= HARVEST_DAY && trays[0].day >= 0);
    digitalWrite(PIN_LED_RED_A, ha ? HIGH : LOW);

    // Red BC: Tray B or C harvest ready
    bool hbc = (trays[1].day >= HARVEST_DAY && trays[1].day >= 0)
             || (trays[2].day >= HARVEST_DAY && trays[2].day >= 0);
    digitalWrite(PIN_LED_RED_BC, hbc ? HIGH : LOW);

    // Buzzer: water alarm rising edge (not every loop)
    if (water_low_alarm && !prev_water_low) {
        for (int b = 0; b < 2; b++) {
            digitalWrite(PIN_BUZZER, HIGH); delay(200);
            digitalWrite(PIN_BUZZER, LOW);  delay(150);
        }
        Serial.println("ALARM: reservoir water low — please refill");
    }

    // Buzzer: one-shot harvest alert per tray
    for (int i = 0; i < 3; i++) {
        if (trays[i].day >= HARVEST_DAY && trays[i].day >= 0 && !harvest_beeped[i]) {
            harvest_beeped[i] = true;
            digitalWrite(PIN_BUZZER, HIGH); delay(400);
            digitalWrite(PIN_BUZZER, LOW);
            Serial.printf("Tray %c: harvest ready (day %d)\n", 'A' + i, trays[i].day);
        }
    }

    prev_water_low = water_low_alarm;
}

// =============================================================================
// Heartbeat LED — call once per loop (non-blocking)
// Slow blink (1000 ms period): system OK
// Fast blink ( 200 ms period): alarm active
// =============================================================================

static void heartbeat_tick() {
    unsigned long interval = water_low_alarm ? 200UL : 1000UL;
    if (millis() - heartbeat_ms >= interval) {
        heartbeat_hi = !heartbeat_hi;
        digitalWrite(PIN_LED_GREEN, heartbeat_hi ? HIGH : LOW);
        heartbeat_ms = millis();
    }
}

// =============================================================================
// OLED display (128×64, text size 1 = 6×8 px per character)
// Layout — 6 rows × 10 px spacing:
//   Row  0:  HH:MM  Day DD/MM        (time and date)
//   Row 10:  Water: OK / LOW REFILL  (reservoir status)
//   Row 20:  A: D03 M 45%            (tray A)
//   Row 30:  B: D07 M 60%            (tray B)
//   Row 40:  C: D10 M 72% HARVEST    (tray C)
//   Row 52:  Pump: idle  next 07:00  (pump status)
// =============================================================================

static void update_display(const DateTime &now) {
    if (!oled_ok) return;

    oled.clearDisplay();
    oled.setTextSize(1);
    oled.setTextColor(SSD1306_WHITE);

    static const char *DOW[] = { "Sun","Mon","Tue","Wed","Thu","Fri","Sat" };
    char buf[22];

    // Row 0: time and date
    snprintf(buf, sizeof(buf), "%02d:%02d %s %02d/%02d",
             now.hour(), now.minute(), DOW[now.dayOfTheWeek()],
             now.day(), now.month());
    oled.setCursor(0, 0);
    oled.print(buf);

    // Row 10: water status
    oled.setCursor(0, 10);
    oled.print(water_low_alarm ? "Water:LOW  REFILL!" : "Water: OK");

    // Rows 20–40: per-tray status
    for (int i = 0; i < 3; i++) {
        oled.setCursor(0, 20 + i * 10);
        if (trays[i].day < 0) {
            snprintf(buf, sizeof(buf), "%c: empty", 'A' + i);
        } else if (trays[i].day <= BLACKOUT_DAYS) {
            snprintf(buf, sizeof(buf), "%c: D%02d germinating", 'A' + i, trays[i].day);
        } else if (trays[i].day >= HARVEST_DAY) {
            snprintf(buf, sizeof(buf), "%c: D%02d M%3d%% HARVEST",
                     'A' + i, trays[i].day, trays[i].moisture);
        } else {
            snprintf(buf, sizeof(buf), "%c: D%02d M%3d%%",
                     'A' + i, trays[i].day, trays[i].moisture);
        }
        oled.print(buf);
    }

    // Row 52: pump status
    oled.setCursor(0, 52);
    if (pump_running) {
        oled.print("Pump: RUNNING");
    } else {
        int next_h = (now.hour() < WATER_HOUR_1) ? WATER_HOUR_1
                   : (now.hour() < WATER_HOUR_2) ? WATER_HOUR_2
                   : WATER_HOUR_1;
        snprintf(buf, sizeof(buf), "Pump: idle  next %02d:00", next_h);
        oled.print(buf);
    }

    oled.display();
}

// =============================================================================
// Serial diagnostics — prints on every loop iteration
// =============================================================================
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
void loop() {
    // 1. Current time
    DateTime now;
    if (rtc_ok) {
        now = rtc.now();
    } else {
        // Degrade gracefully: approximate from compile-time epoch + uptime
        uint32_t approx = DateTime(F(__DATE__), F(__TIME__)).unixtime()
                        + millis() / 1000UL;
        now = DateTime(approx);
    }
    uint32_t now_epoch = now.unixtime();
    uint16_t today     = (uint16_t)(now_epoch / 86400UL);

    // 2. Serial commands
    handle_serial(now_epoch);

    // 3. Button
    if (button_event) {
        button_event = false;
        seed_next_tray(now_epoch);
    }

    // 4. Tray day counters
    for (int i = 0; i < 3; i++)
        trays[i].day = compute_day(trays[i].seed_epoch, now_epoch);

    // 5. Sensors
    water_low_alarm = water_is_low();
    for (int i = 0; i < 3; i++) {
        trays[i].moisture = (trays[i].day >= 0)
                          ? read_moisture(MOISTURE_PINS[i])
                          : 0;
    }

    // 6. Light schedule
    apply_lights(now.hour());

    // 7. Watering schedule
    apply_watering(now.hour(), today);

    // 8. Indicators
    update_indicators();

    // 9. Display
    update_display(now);

    // 10. Serial diagnostics
    print_status(now);

    // 11. Heartbeat tick before sleep
    heartbeat_tick();

    // 12. Light sleep
    //     Relay GPIO outputs are preserved during light sleep (ESP32 datasheet §4.3).
    //     The pump is always switched off before we reach this point.
    //     Pressing the button (GPIO0 LOW) wakes the CPU immediately.
    Serial.printf("Sleeping %d s...\n\n", SLEEP_SECONDS);
    Serial.flush();
    esp_sleep_enable_timer_wakeup((uint64_t)SLEEP_SECONDS * 1000000ULL);
    esp_light_sleep_start();
    // Execution resumes here on wakeup
}

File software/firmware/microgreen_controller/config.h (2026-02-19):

// =============================================================================
// config.h — User-adjustable parameters for Microgreen Box v1.0
// =============================================================================
// Edit these values to match your hardware and growing preferences.
// All times use 24-hour format (0–23).
// After editing, re-flash the ESP32 via Arduino IDE.
// =============================================================================

#pragma once

// ─────────────────────────────────────────────────────────────────────────────
// LIGHT SCHEDULE
// ─────────────────────────────────────────────────────────────────────────────

// Hour (0–23) when grow lights turn ON each day.
#define PHOTO_ON_HOUR    6    // 06:00

// Hour (0–23) when grow lights turn OFF each day.
// Photoperiod = PHOTO_OFF_HOUR − PHOTO_ON_HOUR  (default: 20 − 6 = 14 hours)
#define PHOTO_OFF_HOUR   20   // 20:00

// Days after seeding during which lights remain OFF (germination blackout).
// Day 0 = seeded today. Lights first activate on day (BLACKOUT_DAYS + 1).
// Broccoli: 2 days dark to encourage hypocotyl elongation before light exposure.
#define BLACKOUT_DAYS    2

// ─────────────────────────────────────────────────────────────────────────────
// WATERING SCHEDULE
// ─────────────────────────────────────────────────────────────────────────────

// Hour (0–23) for morning watering event.
#define WATER_HOUR_1     7    // 07:00

// Hour (0–23) for evening watering event.
#define WATER_HOUR_2     19   // 19:00

// Number of days after seeding during which a tray is EXCLUDED from moisture-
// driven watering decisions. Seeds are soaked 4–8 h before sowing and the coir
// is already saturated on day 0. Over-watering days 0–N is the primary cause
// of damping-off (Pythium root rot). Germinating trays still receive water as a
// side-effect when established trays trigger a pump run; they are just not
// allowed to trigger extra pump runs themselves.
// Set equal to BLACKOUT_DAYS (both are 2 for broccoli) — they serve different
// purposes (lighting vs. watering) but share the same value by coincidence.
#define GERMINATION_WATER_DAYS  2

// ─────────────────────────────────────────────────────────────────────────────
// GROW CYCLE
// ─────────────────────────────────────────────────────────────────────────────

// Total grow cycle length in days (broccoli microgreens: typically 10 days).
// Tray is considered "ready to reseed" when day >= GROW_DAYS.
#define GROW_DAYS        10

// Grow day on which the harvest-ready LED and buzzer activate.
// Set 2–3 days before GROW_DAYS as an advance warning.
#define HARVEST_DAY      8

// ─────────────────────────────────────────────────────────────────────────────
// PUMP PARAMETERS
// ─────────────────────────────────────────────────────────────────────────────

// Seconds to run the pump for a full scheduled watering event.
// Target delivery: 75 mL total (25 mL × 3 trays).
//   INTLLAB pump at ~50 mL/min: 90 s
//   INTLLAB pump at ~100 mL/min: 45 s
// Measure your pump's actual flow rate and set accordingly.
#define PUMP_RUN_SECONDS     90

// Seconds to run the pump for a top-up pass (shorter than full event).
// Triggered if any tray reads below MOISTURE_TOPUP_THRESHOLD after settling.
#define PUMP_TOPUP_SECONDS   30

// Seconds to wait after the pump stops before re-reading moisture sensors.
// Coir absorbs water slowly; this delay allows moisture to equalise.
#define MOISTURE_SETTLE_SECONDS  30

// ─────────────────────────────────────────────────────────────────────────────
// MOISTURE THRESHOLDS (0–100 %)
// ─────────────────────────────────────────────────────────────────────────────

// Skip a scheduled watering event if ALL active trays read AT OR ABOVE this.
// Prevents over-watering. Raise if coir stays wet too long (mould risk).
#define MOISTURE_SKIP_THRESHOLD   70

// Run a top-up after the scheduled event if ANY active tray reads AT OR BELOW this
// value (after MOISTURE_SETTLE_SECONDS). Lower if trays dry out too quickly.
#define MOISTURE_TOPUP_THRESHOLD  25

// ─────────────────────────────────────────────────────────────────────────────
// MOISTURE SENSOR CALIBRATION (raw ADC counts, 12-bit = 0–4095)
// ─────────────────────────────────────────────────────────────────────────────
// Run the calibration procedure in installation-guide.md to get your values.
// Defaults are approximate for 3.3 V Capacitive V1.2 sensors.
//
// Capacitive sensor behaviour:
//   Dry air      → high output voltage → high ADC count
//   Submerged    → low  output voltage → low  ADC count

// ADC count with sensor held in dry air (0 % moisture reference)
#define MOISTURE_DRY_RAW   3200

// ADC count with sensor fully submerged in clean water (100 % reference)
#define MOISTURE_WET_RAW   1200

// ─────────────────────────────────────────────────────────────────────────────
// SLEEP INTERVAL
// ─────────────────────────────────────────────────────────────────────────────
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

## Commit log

2026-02-19 Initial release: complete open-source microgreen growing device
    Automated broccoli microgreen growing box — 3D-printed PETG enclosure,
    ESP32 firmware, full documentation and BOM.
    Key features:
    - 30 g/day broccoli microgreens (~200 µmol sulforaphane/day)
    - 12V DC power: solar/LiFePO4, vehicle, or mains adapter
    - Vehicle-compatible: sealed water system, wide low-CG base
    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
    [base_unit.scad, bill-of-materials.csv, growing_tray.scad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]
2026-02-19 Add DECISION-027/028: publication and consistency fixes
    - DECISION-027: document all consistency issues found and fixed before publication
    (ring height 260→190mm, door dims, print strategy quarters vs halves,
    chamber dimensions vs params.scad, filament/time totals)
    - DECISION-028: record open-source publication decision, licence choices,
    GitHub URL, new files added
    - Phase 05 Publication section added to project status table
2026-02-19 Add pre-generated STL files and fix manifold_3way geometry
    STL files (20 parts) generated from OpenSCAD source at $fn=64 (production
    quality) and committed so builders can order prints without installing
    OpenSCAD. Print quantities in Makefile comments and printing-instructions.md.
    Bug fix: misc_parts.scad manifold_3way() was non-manifold (Simple: no,
    Volumes: 5). Two root causes fixed:
    1. All barb cylinders (inlet + 3 outlets) started exactly tangent to the
    body surface — CGAL does not merge touching surfaces. Fixed by overlapping
    each barb 2mm into the body (olap=2.0).
    2. Outlet bore cylinders started at body surface (X=mani_body_d/2) and did
    not reach the inlet bore (radius 2.7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
    [base_front.stl, base_rear.stl, drip_emitter.stl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]
2026-02-19 Clarify STL ordering workflow; fix ring STL filenames in printing-instructions
    README:
    - Lead with pre-built STLs already in repo (hardware/3d-models/stl/)
    - Add Option A (order from print service) with named services
    - Add Option B (print yourself) clearly secondary
    - Both the "What you need" and "Getting started" sections updated
    printing-instructions.md:
    - Add Option A section at top: step-by-step guide to ordering from a
    print service (Craftcloud, JLCPCB, Treatstock, local shop/library)
    - Fix ring STL filenames: ring_front/rear/left/right → ring_FL/FR/RL/RR
    to match actual generated files (DECISION-013 corner quarters)
    - Update ring subtotals (390g/11h per set) and grand total (~7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

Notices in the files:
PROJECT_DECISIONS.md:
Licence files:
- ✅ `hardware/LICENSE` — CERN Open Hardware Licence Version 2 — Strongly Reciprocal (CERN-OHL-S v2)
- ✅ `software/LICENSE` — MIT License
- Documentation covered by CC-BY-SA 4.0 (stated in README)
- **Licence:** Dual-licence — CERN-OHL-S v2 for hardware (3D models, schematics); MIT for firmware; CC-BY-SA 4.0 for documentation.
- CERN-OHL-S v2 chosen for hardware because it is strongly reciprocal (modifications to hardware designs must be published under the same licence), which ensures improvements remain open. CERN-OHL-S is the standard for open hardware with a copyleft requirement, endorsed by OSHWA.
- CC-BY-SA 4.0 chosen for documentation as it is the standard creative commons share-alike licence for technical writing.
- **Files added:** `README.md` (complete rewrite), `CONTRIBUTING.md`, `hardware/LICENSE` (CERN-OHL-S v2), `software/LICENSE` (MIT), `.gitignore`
